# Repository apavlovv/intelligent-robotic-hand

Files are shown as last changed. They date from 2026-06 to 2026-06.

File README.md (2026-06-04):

# Інтелектуальна система керування роботизованою рукою із застосуванням комп'ютерного зору

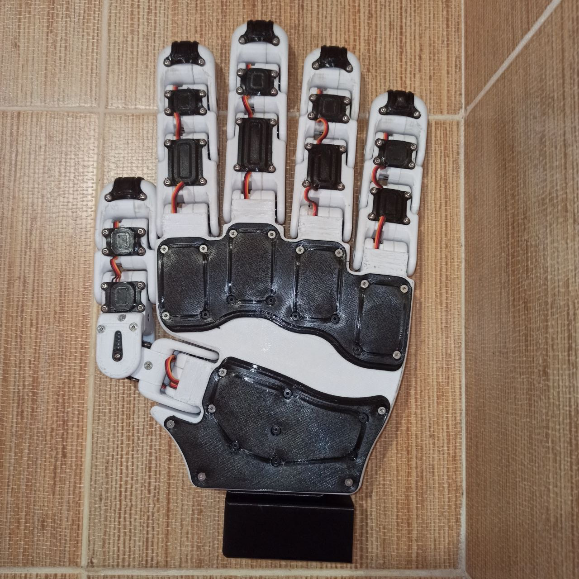
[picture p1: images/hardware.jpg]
Фото маніпулятора

*Зовнішній вигляд розробленого маніпулятора*

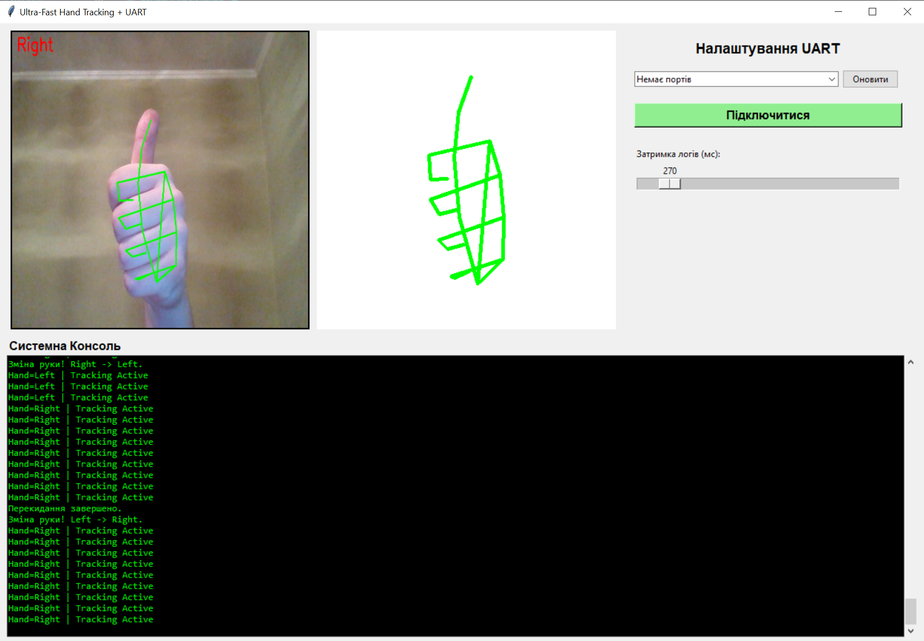
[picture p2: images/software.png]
Скриншот інтерфейсу

*Інтерфейс програми під час відстеження кисті*

Цей репозиторій містить програмне та апаратне забезпечення для безконтактного жестового керування 3D-друкованою антропоморфною роботизованою рукою (16 ступенів свободи). Система працює в «режимі тіні», відтворюючи рухи руки оператора в реальному часі з використанням звичайної веб-камери.

## Основні можливості
* **Безмаркерний трекінг:** Відстеження 21 ключової точки кисті за допомогою MediaPipe.
* **Двоступенева EMA-фільтрація:** Програмне (Python) та апаратне (ESP32S3) згладжування для усунення тремтіння сервоприводів.
* **Автономна логіка:** Підтримка лівої та правої руки з безпечним переходом великого пальця через кінцевий автомат.
* **Висока швидкодія:** Обробка відеопотоку 30-35 FPS із затримкою 60-80 мс.

## Апаратне забезпечення
* **Мікроконтролер:** ESP32S3.
* **ШІМ-драйвер:** 16-канальний PCA9685 (I2C).
* **Виконавчі механізми:** Сервоприводи SG90 та MG90S (16 шт).
* **Живлення:** Окреме джерело 5V, 15A+ для сервоприводів.

## Програмне забезпечення та інсталяція
Проєкт складається з обчислювального ядра на Python та прошивки для ESP32S3.

### 1. Прошивка ESP32S3
Завантажте код з `src/esp32_firmware/` у плату ESP32S3 через Arduino IDE (потрібна бібліотека `Adafruit_PWMServoDriver`).

### 2. Запуск Python-ядра
Переконайтеся, що встановлено Python 3.10+.
```bash
# Встановлення залежностей
pip install -r src/python_cv/requirements.txt

# Запуск
python src/python_cv/main.py

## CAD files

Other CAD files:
hardware/drawings_inventor/КРЕСЛЕНИК 001.idw
hardware/drawings_inventor/КРЕСЛЕНИК 002.idw
hardware/drawings_inventor/КРЕСЛЕНИК 003.idw
hardware/drawings_inventor/КРЕСЛЕНИК 004.idw
hardware/drawings_inventor/КРЕСЛЕНИК 005.idw
hardware/drawings_inventor/КРЕСЛЕНИК 006.idw
hardware/drawings_inventor/КРЕСЛЕНИК 007.idw
hardware/drawings_inventor/КРЕСЛЕНИК 008.idw
hardware/drawings_inventor/КРЕСЛЕНИК 009.idw
hardware/drawings_inventor/КРЕСЛЕНИК 100 СБ.idw
hardware/drawings_inventor/КРЕСЛЕНИК 200 СБ.idw
hardware/drawings_inventor/КРЕСЛЕНИК 300 СБ.idw

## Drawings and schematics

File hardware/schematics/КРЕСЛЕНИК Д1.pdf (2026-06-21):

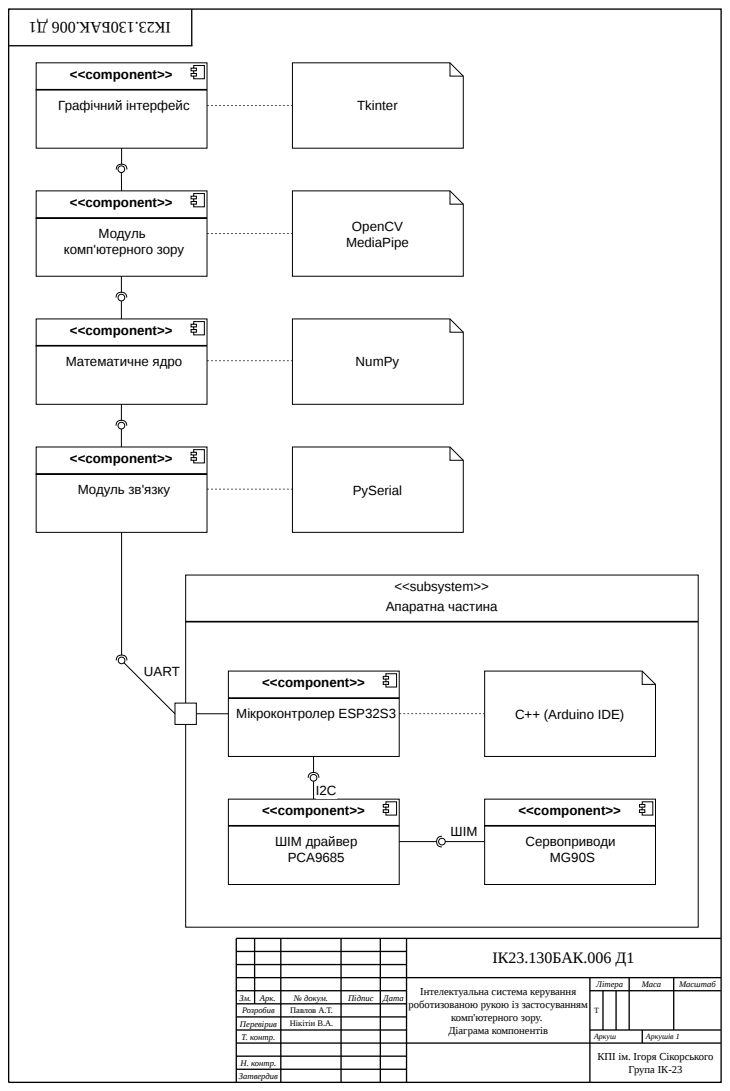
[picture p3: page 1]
ІК23.130БАК.006 Д1; Літера; Маса; Масштаб; Аркуш; Аркушів 1; Затвердив; <<component>>; Графічний інтерфейс; Tkinter; OpenCV MediaPipe; Математичне ядро; NumPy; Модуль зв'язку; PySerial; <<subsystem>> Апаратна частина; Мікроконтролер ESP32S3; C++ (Arduino IDE); UART; ШІМ драйвер PCA9685; Сервоприводи MG90S; ШІМ

Модуль
комп'ютерного зору

Інтелектуальна система керування
роботизованою рукою із застосуванням

Зм. | Арк. | № докум. | Підпис | Дата
Розробив | | Павлов А.Т.
Перевірив | | Нікітін В.А.
Т. контр.

комп'ютерного зору.
Діаграма компонентів

КПІ ім. Ігоря Сікорського
Група ІК-23

Н. контр.

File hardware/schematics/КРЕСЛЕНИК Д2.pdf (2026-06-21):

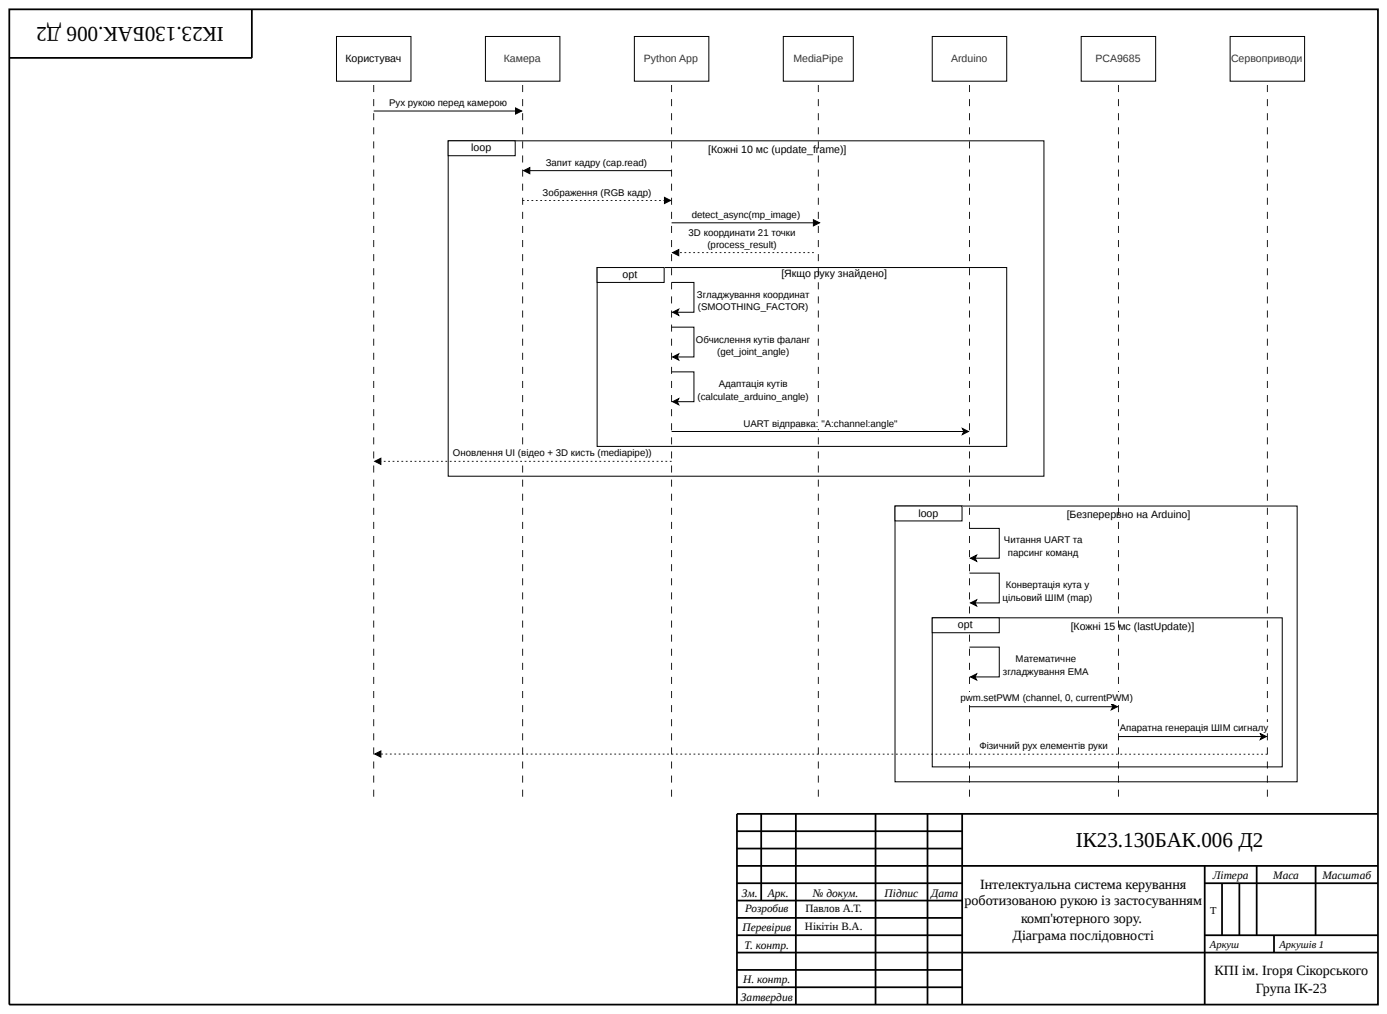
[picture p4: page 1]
ІК23.130БАК.006 Д2; Літера; Маса; Масштаб; Аркуш; Аркушів 1; Затвердив; Користувач; Камера; Python App; MediaPipe; Arduino; PCA9685; Сервоприводи; loop; [Кожні 10 мс (update_frame)]; detect_async(mp_image); 3D координати 21 точки (process_result); Згладжування координат (SMOOTHING_FACTOR); Адаптація кутів (calculate_arduino_angle); opt; [Якщо руку знайдено]; Математичне згладжування EMA

Рух рукою перед камерою

Запит кадру (cap.read)

Зображення (RGB кадр)

Обчислення кутів фаланг
(get_joint_angle)

UART відправка: "A:channel:angle"

Оновлення UI (відео + 3D кисть (mediapipe))

[Безперервно на Arduino]

Читання UART та
парсинг команд

Конвертація кута у
цільовий ШІМ (map)

[Кожні 15 мс (lastUpdate)]

pwm.setPWM (channel, 0, currentPWM)

Апаратна генерація ШІМ сигналу

Фізичний рух елементів руки

Інтелектуальна система керування
роботизованою рукою із застосуванням

Зм. | Арк. | № докум. | Підпис | Дата
Розробив | | Павлов А.Т.
Перевірив | | Нікітін В.А.
Т. контр.

комп'ютерного зору.
Діаграма послідовності

КПІ ім. Ігоря Сікорського
Група ІК-23

Н. контр.

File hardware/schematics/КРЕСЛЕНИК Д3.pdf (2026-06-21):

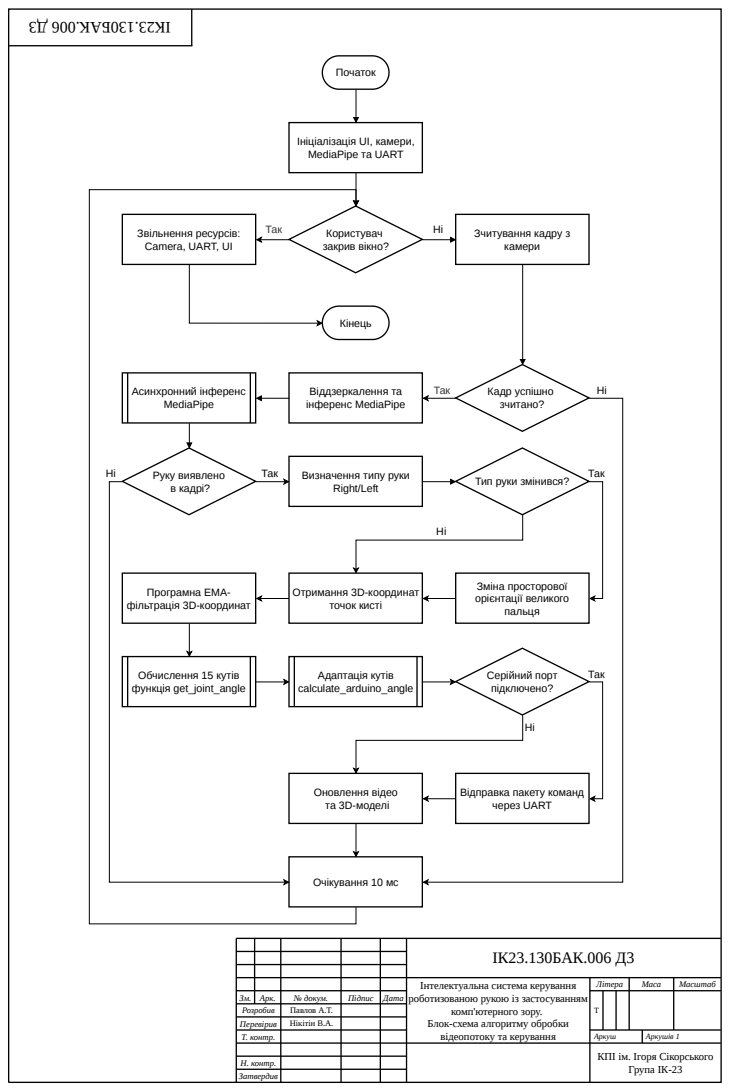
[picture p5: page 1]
ІК23.130БАК.006 Д3; Літера; Маса; Масштаб; Аркуш; Аркушів 1; Затвердив; Початок; Так; Користувач; закрив вікно?; Кінець; Зчитування кадру з камери; Кадр успішно; зчитано?; Очікування 10 мс; Віддзеркалення та інференс MediaPipe; Асинхронний інференс MediaPipe; Руку виявлено; в кадрі?; Зміна просторової орієнтації великого пальця; Отримання 3D-координат точок кисті; Програмна ЕМА- фільтрація 3D-координат; Обчислення 15 кутів функція get_joint_angle; Адаптація кутів calculate_arduino_angle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

Ініціалізація UI, камери,
MediaPipe та UART

Звільнення ресурсів:
Camera, UART, UI

Визначення типу руки
Right/Left

Тип руки змінився?

Відправка пакету команд
через UART

Інтелектуальна система керування
роботизованою рукою із застосуванням

Зм. | Арк. | № докум. | Підпис | Дата
Розробив | | Павлов А.Т.
Перевірив | | Нікітін В.А.
Т. контр.

комп'ютерного зору.
Блок-схема алгоритму обробки
відеопотоку та керування

КПІ ім. Ігоря Сікорського
Група ІК-23

Н. контр.

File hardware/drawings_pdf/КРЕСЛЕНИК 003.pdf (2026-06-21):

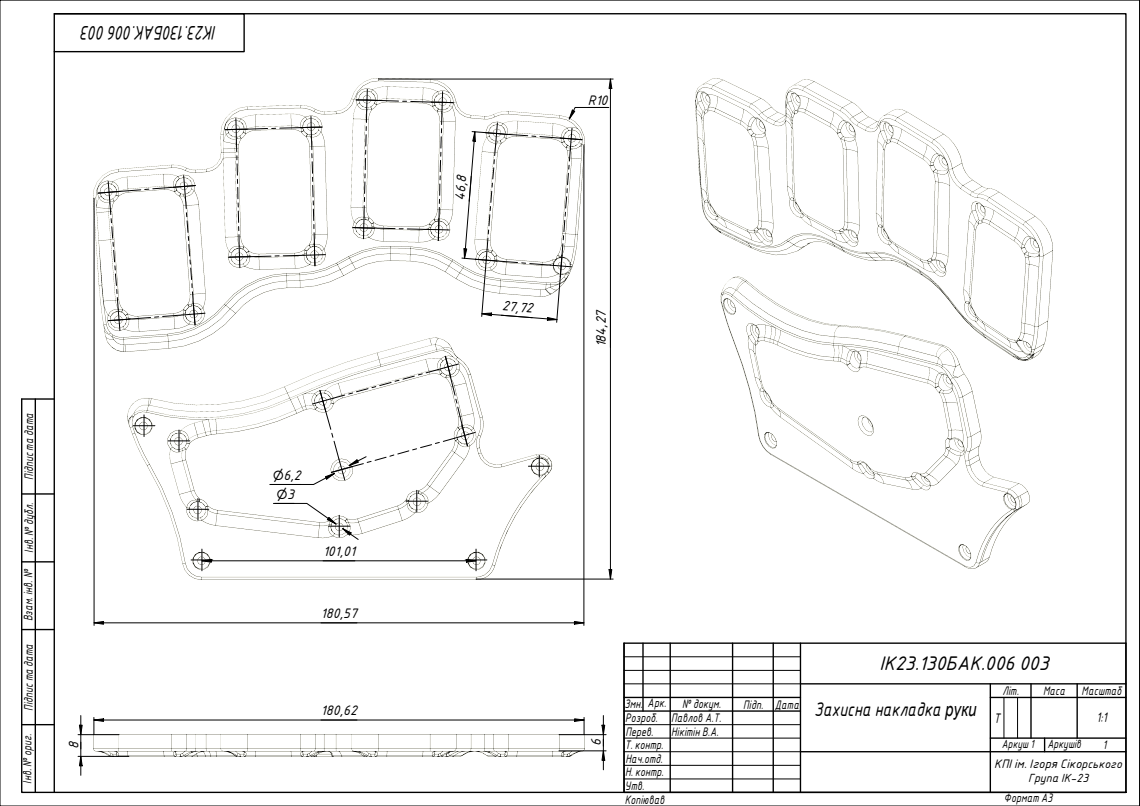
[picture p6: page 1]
Формат A3; Інв. № ор; иг. Під; м. інв. № Інв. №; бл. Під

ІК23.130БАК.006 003

Захисна накладка руки | Літ. | Маса | Масштаб

Змн. | Арк. | № докум. | Підп. | Дата | | Т | | | 1:1
Розроб. | | Павлов А.Т.
Перев. | | Нікітін В.А.
Т. контр. | | | | | Аркуш 1 | Аркушів 1
Нач.отд. | | | | | КПІ ім. Ігоря Сікорського Група ІК-23
Н. контр.
Утв.

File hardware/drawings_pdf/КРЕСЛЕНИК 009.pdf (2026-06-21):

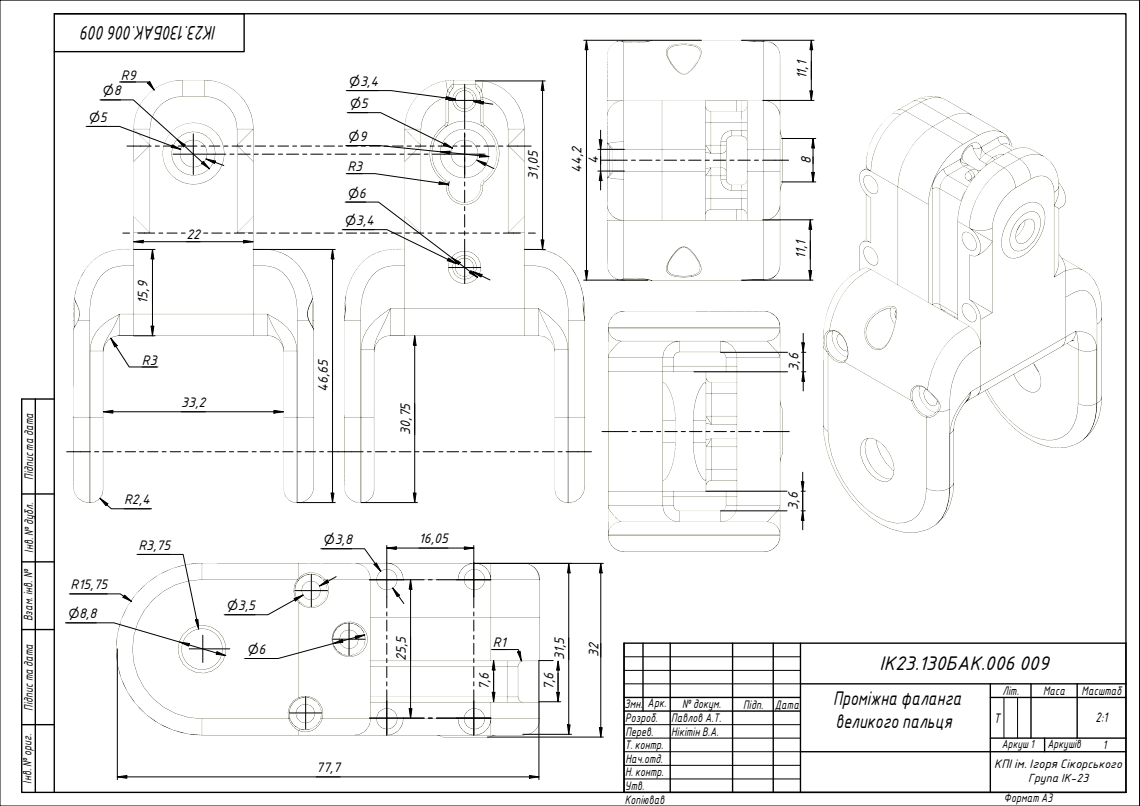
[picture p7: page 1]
б. Перев. Т. контр. Н. контр. Утв.; Літ.

Інв. № ориг. Підпис та дата Взам. інв. № Інв. № дубл. Підпис та дата

А.Т. Нікітін В.А. | | | ІК2 Пр о м іж н а ф а л а н г а в е л и к о г о п а л ь ц я | | а с а | М а с ш т а б

н. З м | А р к. | № д о к у м. | Пі д п. | Д а т а | | Т | | | 2 :
Р о з р о | | а в л о в

Н а ч.о т | | КПІ ім. І г о р я Сік о р с ь к о г о Гр у п а ІК -2 3

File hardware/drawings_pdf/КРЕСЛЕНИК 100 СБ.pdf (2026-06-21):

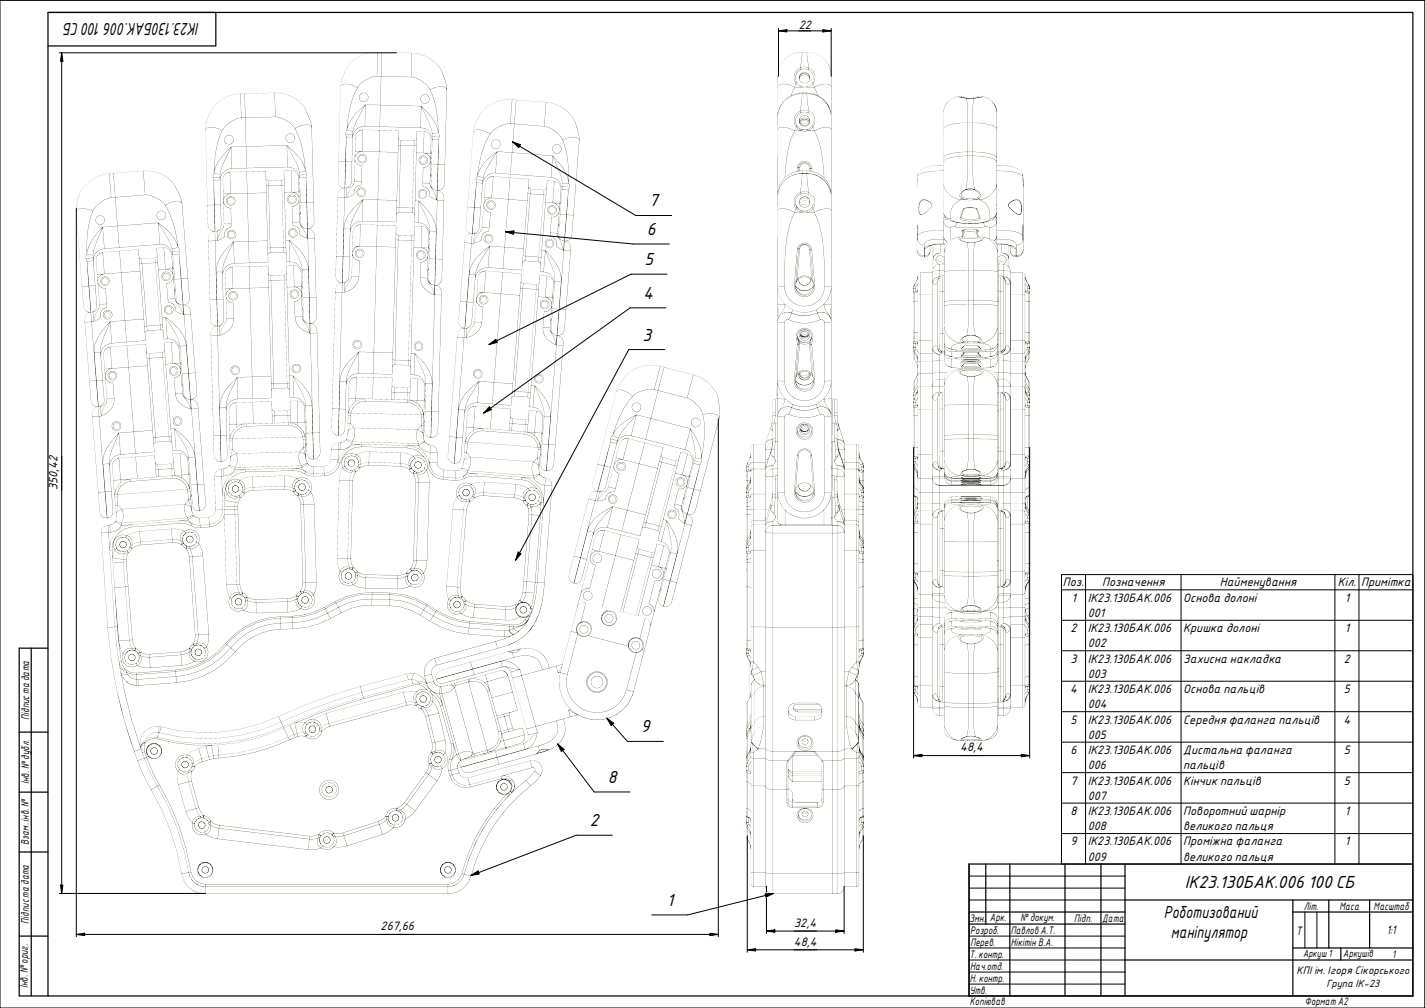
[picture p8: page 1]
б. Перев. Т. контр. Н. контр. Утв.; Літ.

П о з. | П о з н а ч е н н я | Н а й м е н у в а н н я | Кіл. | Пр и м іт к а
1 | ІК2 3.13 0 Б А К.0 0 6 0 0 1 | О с н о в а д о л о н і | 1

Інв. № ориг. Підпис та дата Взам. інв. № Інв. № дубл. Підпис та дата

7 | ІК2 3.13 0 Б А К.0 0 6 0 0 7 | Кін ч и к п а л ь ц і в | 5

А.Т. Нікітін В.А. | | | ІК2 Р о б о т и з о в а н и й м а н іп у л я т о р | | а с а | М а с ш т а б

З м н. | А р к. | № д о к у м. | Пі д п. | Д а т а | | Т | | | 1:
Р о зр о | | а в л о в

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

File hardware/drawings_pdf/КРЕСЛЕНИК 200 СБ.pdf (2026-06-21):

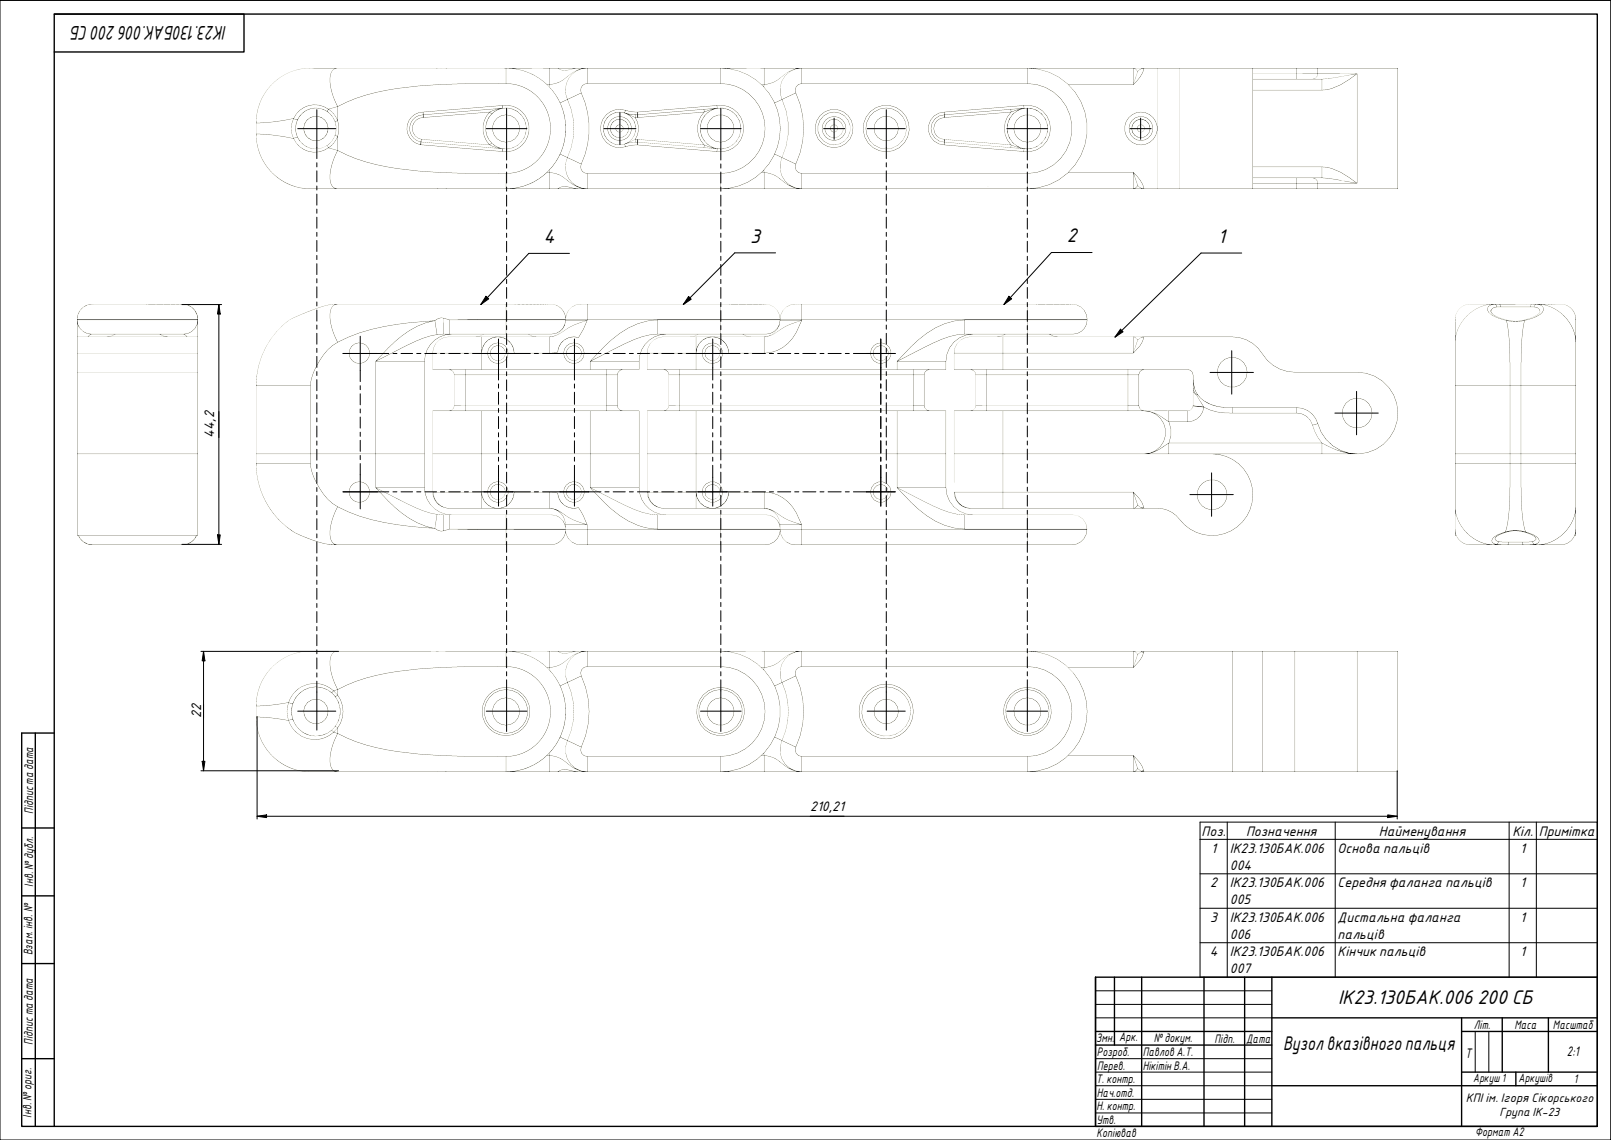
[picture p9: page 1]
Формат A2; Інв. № ор; иг. Під; м. інв. № Інв. №; бл. Під

Поз. | Позначення | Найменування | Кіл. | Примітка
1 | ІК23.130БАК.006 004 | Основа пальців | 1

2 | ІК23.130БАК.006 005 | Середня фаланга пальців | 1

3 | ІК23.130БАК.006 006 | Дистальна фаланга пальців | 1

4 | ІК23.130БАК.006 007 | Кінчик пальців | 1

ІК23.130БАК.006 200 СБ

Вузол вказівного пальця | Літ. | Маса | Масштаб

Змн. | Арк. | № докум. | Підп. | Дата | | Т | | | 2:1
Розроб. | | Павлов А.Т.
Перев. | | Нікітін В.А.
Т. контр. | | | | | Аркуш 1 | Аркушів 1
Нач.отд. | | | | | КПІ ім. Ігоря Сікорського Група ІК-23
Н. контр.
Утв.

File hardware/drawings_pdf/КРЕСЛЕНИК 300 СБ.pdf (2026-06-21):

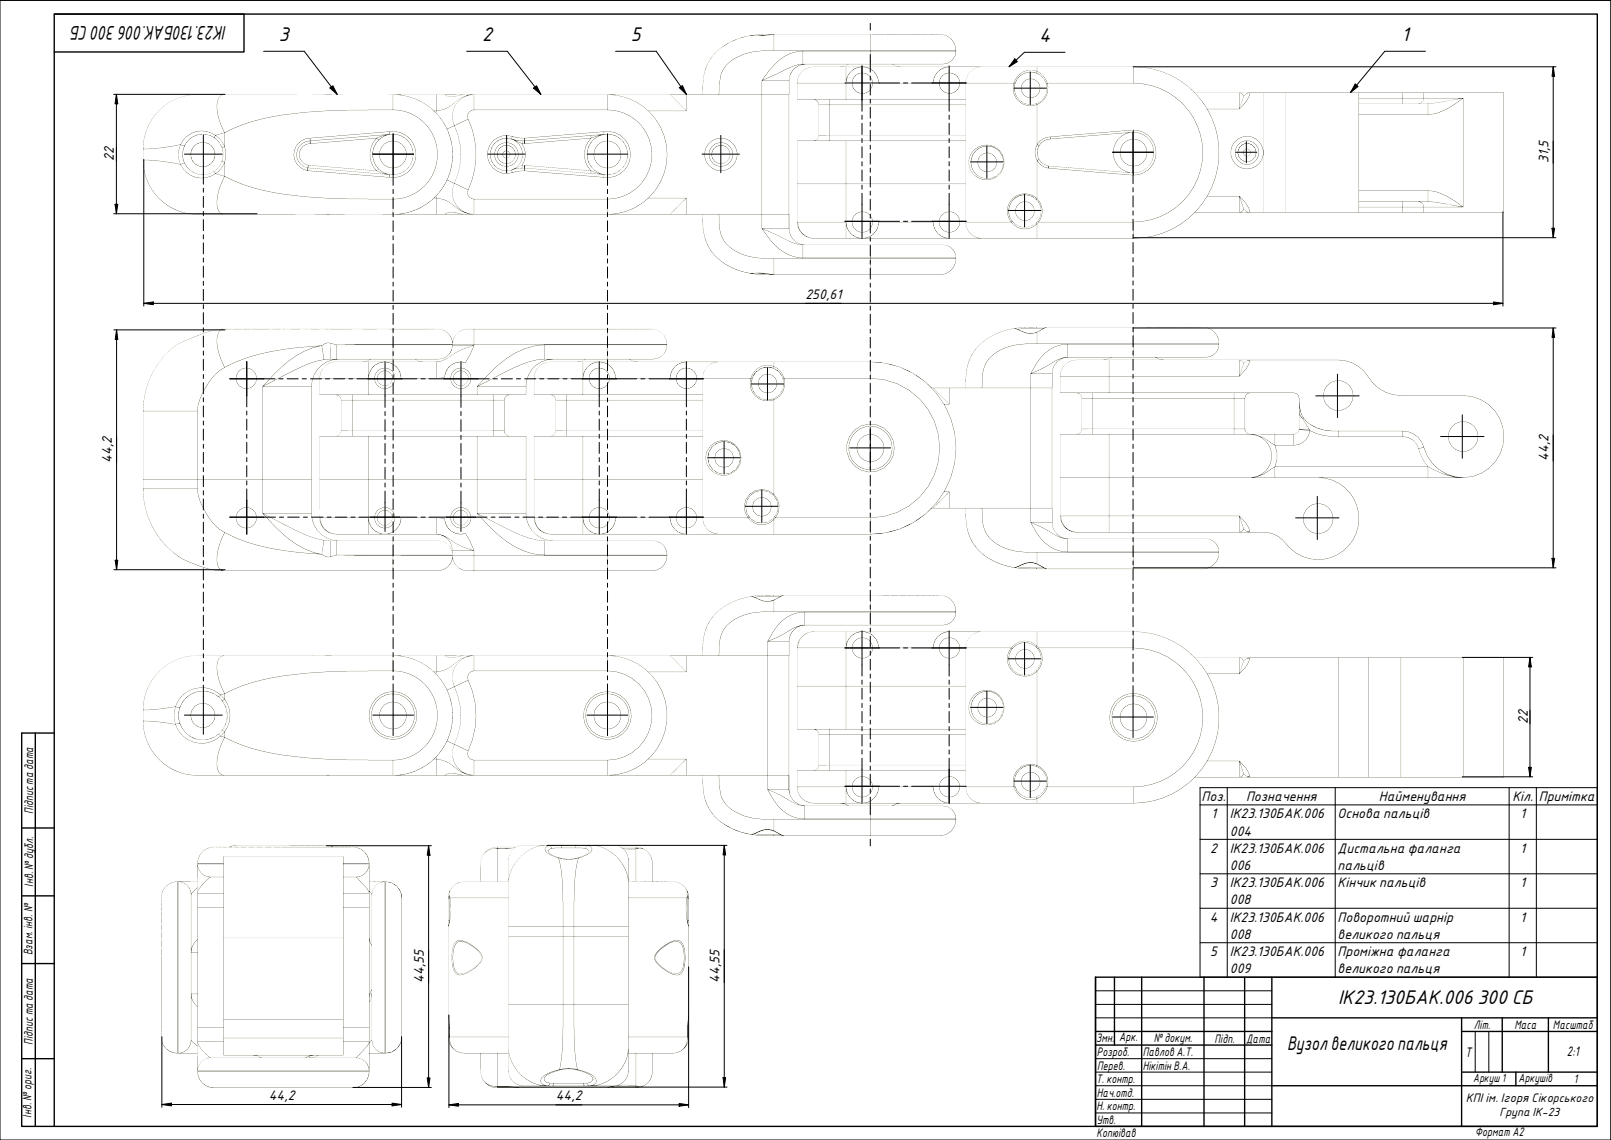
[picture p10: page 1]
Формат A2; Інв. № ор; иг. Під; м. інв. № Інв. №; бл. Під

Поз. | Позначення | Найменування | Кіл. | Примітка
1 | ІК23.130БАК.006 004 | Основа пальців | 1

2 | ІК23.130БАК.006 006 | Дистальна фаланга пальців | 1

3 | ІК23.130БАК.006 008 | Кінчик пальців | 1

4 | ІК23.130БАК.006 008 | Поворотний шарнір великого пальця | 1

5 | ІК23.130БАК.006 009 | Проміжна фаланга великого пальця | 1

ІК23.130БАК.006 300 СБ

Вузол великого пальця | Літ. | Маса | Масштаб

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

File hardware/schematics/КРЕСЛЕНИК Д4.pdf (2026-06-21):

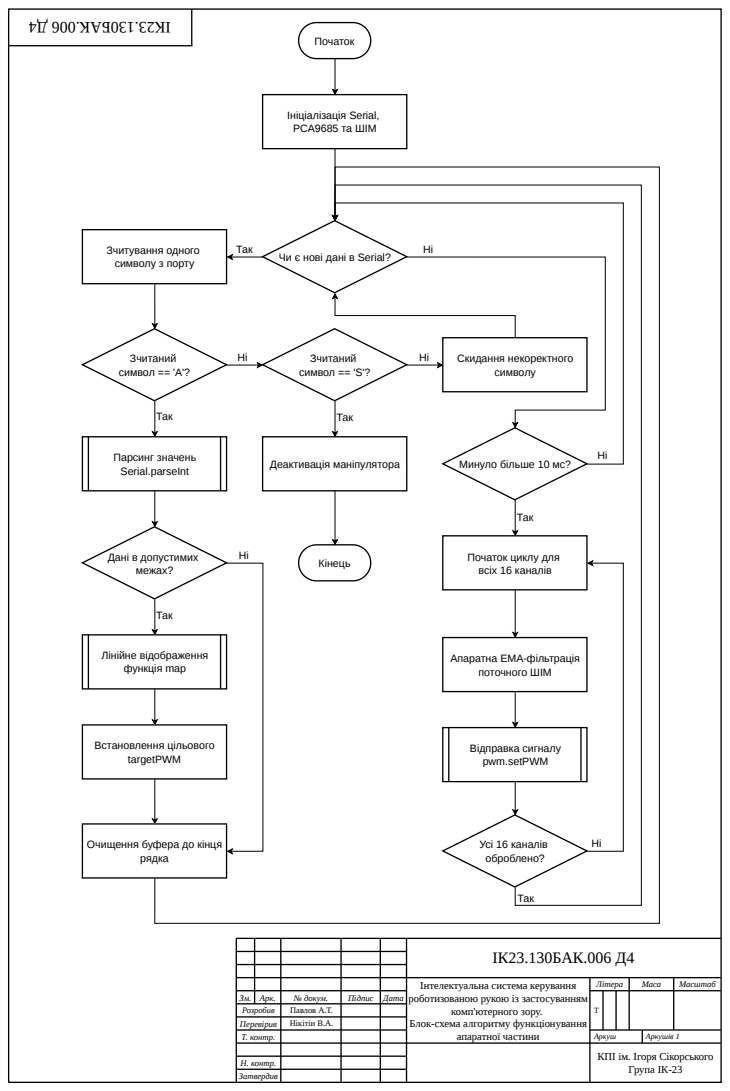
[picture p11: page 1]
апаратної частини; ІК23.130БАК.006 Д4; Літера; Маса; Масштаб; Аркуш; Аркушів 1; Затвердив; Ініціалізація Serial, PCA9685 та ШІМ; Так; Ні Чи є нові дані в Serial? Зчитування одного; символу з порту; Зчитаний символ == 'A'?; Скидання некоректного символу; Парсинг значень Serial.parseInt; Дані в допустимих; межах?; Лінійне відображення функція map; Встановлення цільового targetPWM; рядка; Відправка сигналу pwm.setPWM; Усі 16 каналів оброблено?; Початок; Кінець; Зчитаний символ == 'S'?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

Минуло більше 10 мс?

Початок циклу для
всіх 16 каналів

Апаратна ЕМА-фільтрація
поточного ШІМ

Очищення буфера до кінця

Інтелектуальна система керування
роботизованою рукою із застосуванням

Зм. | Арк. | № докум. | Підпис | Дата
Розробив | | Павлов А.Т.
Перевірив | | Нікітін В.А.
Т. контр.

комп'ютерного зору.

Блок-схема алгоритму функціонування

КПІ ім. Ігоря Сікорського
Група ІК-23

Н. контр.

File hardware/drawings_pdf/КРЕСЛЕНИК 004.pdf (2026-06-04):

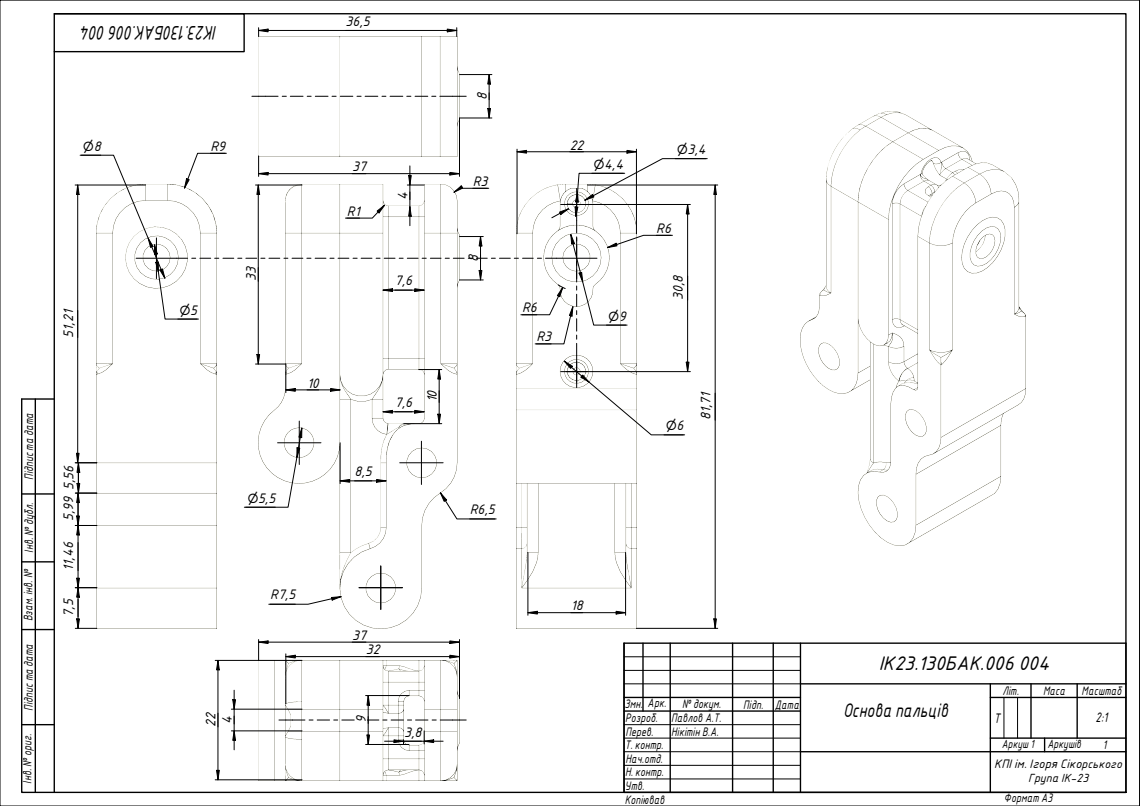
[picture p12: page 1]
Формат A3; ІК23.130БАК.006 004; Інв. № ор; иг. Під; м. інв. № Інв. №; бл. Під

Основа пальців | Літ. | Маса | Масштаб

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

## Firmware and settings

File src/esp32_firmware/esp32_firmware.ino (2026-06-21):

#include <Wire.h>
#include <Adafruit_PWMServoDriver.h>
#include <Preferences.h>

#define I2C_SDA 8
#define I2C_SCL 9

Adafruit_PWMServoDriver pwm = Adafruit_PWMServoDriver();
Preferences preferences;

struct ServoConfig {
  int minPWM; 
  int midPWM; 
  int maxPWM; 
};

struct ServoState {
  float currentPWM;
  int targetPWM;
};

// СТАНДАРТНІ ЗНАЧЕННЯ ЗІ СКРІНШОТУ
ServoConfig defaultServos[16] = {
  {135, 324, 500}, // Канал 0
  {166, 348, 500}, // Канал 1
  {177, 348, 500}, // Канал 2
  {188, 355, 500}, // Канал 3
  {188, 328, 500}, // Канал 4
  {130, 315, 500}, // Канал 5  
  {200, 353, 500}, // Канал 6
  {158, 328, 400}, // Канал 7
  {140, 344, 500}, // Канал 8
  {150, 329, 500}, // Канал 9
  {155, 326, 500}, // Канал 10
  {125, 285, 500}, // Канал 11 
  {115, 282, 500}, // Канал 12 
  {144, 326, 500}, // Канал 13
  {133, 333, 500}, // Канал 14
  {144, 333, 500}  // Канал 15
};

ServoConfig servos[16];
ServoState states[16];

const float EMA_ALPHA = 0.4;
const int FAST_SERVO = 6;
unsigned long lastUpdate = 0;

void setup() {
  Serial.begin(115200);
  Serial.setTimeout(10); 
  Wire.begin(I2C_SDA, I2C_SCL);

  pwm.begin();
  pwm.setOscillatorFrequency(27000000);
  pwm.setPWMFreq(50);

  preferences.begin("bionic_hand", false);
  
  size_t configSize = preferences.getBytesLength("servo_cfg_v3");
  if (configSize == sizeof(servos)) {
    preferences.getBytes("servo_cfg_v3", servos, sizeof(servos));
    Serial.println("INFO: Налаштування завантажено з NVS.");
  } else {
    memcpy(servos, defaultServos, sizeof(servos));
    preferences.putBytes("servo_cfg_v3", servos, sizeof(servos));
    Serial.println("INFO: Стандартні ліміти збережено в пам'ять.");
  }

  for (int i = 0; i < 16; i++) {
    states[i].currentPWM = -1;
    states[i].targetPWM = -1;
  }
  delay(10);
}

int calculatePWM(int channel, int angle) {
  if (angle <= 90) {
    return map(angle, 0, 90, servos[channel].minPWM, servos[channel].midPWM);
  } else {
    return map(angle, 90, 180, servos[channel].midPWM, servos[channel].maxPWM);
  }
}

void disableUnusedServos(uint16_t activeMask) {
  for (int i = 0; i < 16; i++) {
    if ((activeMask & (1 << i)) == 0) {
      if (states[i].targetPWM != -1) {
        pwm.setPWM(i, 0, 0); 
        states[i].targetPWM = -1; 
        states[i].currentPWM = -1; 
      }
    }
  }
}

void loop() {
  if (Serial.available() > 0) {
    String command = Serial.readStringUntil('\n');
    command.trim();
    
    if (command.length() > 0) {
      char cmdType = command.charAt(0);
      
      if (cmdType == 'A') {
        int channel, angle;
        if (sscanf(command.c_str(), "A,%d,%d", &channel, &angle) == 2) {
          if (channel >= 0 && channel < 16 && angle >= 0 && angle <= 180) {
            int target = calculatePWM(channel, angle);
            states[channel].targetPWM = target;
            if (states[channel].currentPWM == -1) {
              states[channel].currentPWM = target;
              pwm.setPWM(channel, 0, target);
            }
          }
        }
      }
      else if (cmdType == 'X') {
        uint16_t mask;
        if (sscanf(command.c_str(), "X,%hu", &mask) == 1) {
          disableUnusedServos(mask);
        }
      }
      else if (cmdType == 'W') {
        uint16_t mask;
        int pwmVal;
        if (sscanf(command.c_str(), "W,%hu,%d", &mask, &pwmVal) == 2) {
          disableUnusedServos(mask);
          for (int i = 0; i < 16; i++) {
            if (mask & (1 << i)) { 
              states[i].targetPWM = pwmVal;
              if (states[i].currentPWM == -1) {
                states[i].currentPWM = pwmVal;
                pwm.setPWM(i, 0, pwmVal);
              }
            }
          }
        }
      }
      else if (cmdType == 'G') {
        uint16_t mask;
        int angle;
        if (sscanf(command.c_str(), "G,%hu,%d", &mask, &angle) == 2) {
          if (angle >= 0 && angle <= 180) {
            disableUnusedServos(mask);
            for (int i = 0; i < 16; i++) {
              if (mask & (1 << i)) {
                int target = calculatePWM(i, angle);
                states[i].targetPWM = target;
                if (states[i].currentPWM == -1) {
                  states[i].currentPWM = target;
                  pwm.setPWM(i, 0, target);
                }
              }
            }
          }
        }
      }
      else if (cmdType == 'C') {
        int channel, minP, midP, maxP;
        if (sscanf(command.c_str(), "C,%d,%d,%d,%d", &channel, &minP, &midP, &maxP) == 4) {
          if (channel >= 0 && channel < 16) {
            servos[channel].minPWM = minP;
            servos[channel].midPWM = midP;
            servos[channel].maxPWM = maxP;
            Serial.printf("OK: Конфіг серво %d оновлено\n", channel);
          }
        }
      }
      else if (cmdType == 'S') {
        preferences.putBytes("servo_cfg_v3", servos, sizeof(servos));
        Serial.println("OK: Всі налаштування збережено у флеш-пам'ять!");
      }
      else if (cmdType == 'R') {
        for (int i = 0; i < 16; i++) {
          Serial.printf("CFG,%d,%d,%d,%d\n", i, servos[i].minPWM, servos[i].midPWM, servos[i].maxPWM);
        }
        Serial.println("OK: Дані відправлено");
      }
    }
  }

  unsigned long currentMillis = millis();
  if (currentMillis - lastUpdate >= 15) {
    lastUpdate = currentMillis;
    for (int i = 0; i < 16; i++) {
      if (states[i].targetPWM != -1 && abs(states[i].currentPWM - states[i].targetPWM) > 0.1) {
        if (i == FAST_SERVO) {
          states[i].currentPWM = states[i].targetPWM;
        } else {
          states[i].currentPWM = (EMA_ALPHA * states[i].targetPWM) + ((1.0 - EMA_ALPHA) * states[i].currentPWM);
          if (abs(states[i].targetPWM - states[i].currentPWM) < 1.0) {
            states[i].currentPWM = states[i].targetPWM;
          }
        }
        pwm.setPWM(i, 0, (int)states[i].currentPWM);
      }
    }
  }
}

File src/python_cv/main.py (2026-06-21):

import os
import tkinter as tk
from tkinter import ttk
from PIL import Image, ImageTk
import cv2
import numpy as np
import time
import serial
import serial.tools.list_ports
import mediapipe as mp
from mediapipe.tasks import python
from mediapipe.tasks.python import vision

# ==========================================
# ШЛЯХ ДО МОДЕЛІ MediaPipe
# ==========================================
MP_MODEL_PATH = r"C:\Models\hand_landmarker.task"

CONNECTIONS = [
    (0, 1), (1, 2), (2, 3), (3, 4), (0, 5), (5, 6), (6, 7), (7, 8), 
    (5, 9), (9, 10), (10, 11), (11, 12), (9, 13), (13, 14), (14, 15), 
    (15, 16), (13, 17), (0, 17), (17, 18), (18, 19), (19, 20)
]

def get_joint_angle(p1, p2, p3, clamp=True):
    v1 = np.array(p1) - np.array(p2)
    v2 = np.array(p3) - np.array(p2)
    norm1 = np.linalg.norm(v1)
    norm2 = np.linalg.norm(v2)
    if norm1 == 0 or norm2 == 0:
        return 180.0
    dot = np.dot(v1, v2)
    cos_theta = np.clip(dot / (norm1 * norm2), -1.0, 1.0)
    angle = np.degrees(np.arccos(cos_theta))
    if clamp:
        return np.clip(angle, 90.0, 180.0)
    return angle

class HandTrackerApp:
    def __init__(self, root):
        self.root = root
        self.root.title("Bionic Hand Control Center")
        self.root.geometry("1300x1000")
        self.root.protocol("WM_DELETE_WINDOW", self.on_closing)

        self.current_result = None
        self.timestamp = 0
        self.previous_pts_3d = None
        self.previous_is_flipped = False
        self.SMOOTHING_FACTOR = 0.5 
        
        self.current_hand = None        
        self.target_hand = None
        self.thumb_transition = False   
        self.thumb_transition_start = 0 

        self.smoothed_angles = [90.0] * 16 

        self.ser = None
        self.is_connected = False
        self.last_log_time = time.time()
        self.last_serial_send_time = time.time()

        base_options = python.BaseOptions(model_asset_path=MP_MODEL_PATH)
        options = vision.HandLandmarkerOptions(
            base_options=base_options,
            num_hands=1,
            running_mode=vision.RunningMode.LIVE_STREAM,
            result_callback=self.process_result
        )
        self.landmarker = vision.HandLandmarker.create_from_options(options)
        
        self.cap = cv2.VideoCapture(0)

        self.setup_ui()
        self.refresh_ports()
        
        self.update_frame()

    def process_result(self, result, output_image, timestamp):
        self.current_result = result

    def setup_ui(self):
        main_frame = tk.Frame(self.root)
        main_frame.pack(fill=tk.BOTH, expand=True, padx=10, pady=5)

        uart_frame = tk.Frame(main_frame, bd=2, relief=tk.GROOVE)
        uart_frame.pack(fill=tk.X, pady=5, ipadx=5, ipady=5)
        
        tk.Label(uart_frame, text="UART Підключення:", font=("Arial", 12, "bold")).pack(side=tk.LEFT, padx=10)
        self.port_var = tk.StringVar()
        self.port_dropdown = ttk.Combobox(uart_frame, textvariable=self.port_var, state="readonly", width=15)
        self.port_dropdown.pack(side=tk.LEFT, padx=5)
        ttk.Button(uart_frame, text="Оновити", command=self.refresh_ports).pack(side=tk.LEFT, padx=5)
        
        self.btn_connect = tk.Button(uart_frame, text="Підключитися", bg="lightgreen", font=("Arial", 10, "bold"), command=self.toggle_connection)
        self.btn_connect.pack(side=tk.LEFT, padx=15)

        tk.Label(uart_frame, text="Затримка логів (мс):").pack(side=tk.LEFT, padx=5)
        self.delay_slider = tk.Scale(uart_frame, from_=100, to=2000, orient=tk.HORIZONTAL, length=150)
        self.delay_slider.set(500)
        self.delay_slider.pack(side=tk.LEFT, padx=5)

        self.notebook = ttk.Notebook(main_frame)
        self.notebook.pack(fill=tk.BOTH, expand=True, pady=10)

        self.tab_calib = tk.Frame(self.notebook)
        self.tab_group = tk.Frame(self.notebook)
        self.tab_track = tk.Frame(self.notebook)

        self.notebook.add(self.tab_calib, text="1. Калібрування та Таблиця")
        self.notebook.add(self.tab_group, text="2. Груповий тест (Кути)")
        self.notebook.add(self.tab_track, text="3. Трекінг (MediaPipe)")

        self.setup_tab_calib()
        self.setup_tab_group()
        self.setup_tab_track()

        bottom_frame = tk.Frame(main_frame)
        bottom_frame.pack(fill=tk.X, pady=5)
        tk.Label(bottom_frame, text="Системна Консоль", font=("Arial", 10, "bold")).pack(anchor=tk.W)
        scroll = tk.Scrollbar(bottom_frame)
        scroll.pack(side=tk.RIGHT, fill=tk.Y)
        self.console_text = tk.Text(bottom_frame, height=8, bg="black", fg="lime", font=("Consolas", 10), yscrollcommand=scroll.set)
        self.console_text.pack(side=tk.LEFT, fill=tk.X, expand=True)
        scroll.config(command=self.console_text.yview)

        self.log("SYSTEM: Інтерфейс завантажено.")

    def setup_tab_calib(self):
        top_split = tk.PanedWindow(self.tab_calib, orient=tk.HORIZONTAL)
        top_split.pack(fill=tk.BOTH, expand=True, padx=10, pady=10)

        ctrl_frame = tk.Frame(top_split, relief=tk.RIDGE, bd=2)
        top_split.add(ctrl_frame, width=400)

        tk.Label(ctrl_frame, text="Управління каналом", font=("Arial", 12, "bold")).pack(pady=10)
        
        row1 = tk.Frame(ctrl_frame)
        row1.pack(pady=5)
        tk.Label(row1, text="Канал Серво (0-15):").pack(side=tk.LEFT, padx=5)
        self.calib_channel = ttk.Combobox(row1, values=list(range(16)), state="readonly", width=5)
        self.calib_channel.current(0)
        self.calib_channel.pack(side=tk.LEFT, padx=5)
        self.calib_channel.bind("<<ComboboxSelected>>", self.on_calib_channel_change)

        tk.Label(ctrl_frame, text="Тест ШІМ (рухати для перевірки):").pack(pady=(15, 0))
        self.calib_pwm_slider = tk.Scale(ctrl_frame, from_=100, to=500, orient=tk.HORIZONTAL, length=300, command=self.on_calib_slider)
        self.calib_pwm_slider.set(300)
        self.calib_pwm_slider.pack(pady=5)

        grid_frame = tk.Frame(ctrl_frame)
        grid_frame.pack(pady=15)
        tk.Label(grid_frame, text="Min (0°)").grid(row=0, column=0)
        tk.Label(grid_frame, text="Mid (90°)").grid(row=0, column=1)
        tk.Label(grid_frame, text="Max (180°)").grid(row=0, column=2)
        
        self.entry_min = tk.Entry(grid_frame, width=8, justify="center")
        self.entry_min.grid(row=1, column=0, padx=5)
        self.entry_mid = tk.Entry(grid_frame, width=8, justify="center")
        self.entry_mid.grid(row=1, column=1, padx=5)
        self.entry_max = tk.Entry(grid_frame, width=8, justify="center")
        self.entry_max.grid(row=1, column=2, padx=5)

        tk.Button(ctrl_frame, text="Відправити Ліміти в RAM", bg="lightblue", command=self.send_calibration).pack(pady=10, fill=tk.X, padx=20)
        tk.Button(ctrl_frame, text="Зберегти в NVS (Flash)", bg="orange", command=self.send_save).pack(pady=5, fill=tk.X, padx=20)
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
